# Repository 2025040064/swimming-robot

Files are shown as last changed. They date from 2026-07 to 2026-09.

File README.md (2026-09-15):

# 水面垃圾清理机器人（STM32F103C8T6 + K230 + MPU6050）

当前软件使用船底被动滤网，已移除回收机构电机控制；MPU6050 按 +X 朝上、+Y 朝船头安装，提供倾斜限推力和锁定停机保护。两个水平推进器不能主动调平。新增 0.96 寸 OLED 实时显示原始六轴、姿态、校准进度、运行状态和推进 PWM，详见 [OLED 接线与显示](first_0_1/docs/OLED接线与显示.md)。

当前已选择 **MPU6050 电机台架测试模式**（`User/bsp/test/bsp_mpu_motor_test.h` 中 `ROBOT_IMU_MOTOR_TEST_ENABLE=1`）：静止校准约 3 秒后，左右推进电机自动缓慢起转，随倾角增大而减速；运行 30 秒后停止，倾角超限或 MPU6050 数据异常也会停机。测试绕过视觉和超声波条件。上电前固定船身并确保桨叶周围无人接触，详见 [MPU6050 电机测试](first_0_1/docs/MPU6050电机测试.md)。

用户计划三个超声波探头完全浸水，但现有 AJ-SR04M 驱动使用空气测距换算。因此关闭台架测试后，自动运行配置仍进入 `RANGE_HOLD`，待水下测距硬件和驱动确认。参数与待确认项见 [滤网模式与倾角保护](first_0_1/docs/滤网模式与倾角保护.md)。

当前硬件不使用 GPS。K230 使用 USART1；MPU6050 使用硬件 I2C1；第一块 D153C 双路 TB6612 模块负责左右推进。OLED 使用 PB10/PB11 上的独立软件 I2C，默认 SSD1306 128×64，实际屏幕驱动型号尚待确认。

## 固定引脚

- K230：PA9=TX、PA10=RX，3.3 V TTL。
- MPU6050：PB8=SCL、PB9=SDA，3.3 V 供电，SCL/SDA 各一只 4.7 kΩ 上拉到 3.3 V。
- OLED：PB10=SCK、PB11=SDA、3.3 V=VDD、GND 共地；先断开 PB10/PB11 原回收 PWM 接线。
- 前超声：PA6=Trig、PA7=Echo；左超声：PB5=Trig、PB6=Echo；右超声：PB3=Trig、PB4=Echo。三个 Echo 都必须先降压至 3.3 V。
- PA13/PA14 保留为 SWD；PB2 不使用。

## D153C TB6612 模块

第一块 D153C：A 路（AO1/AO2）接左推进，B 路（BO1/BO2）接右推进。

```text
PWMA=PA0  AIN1=PB12  AIN2=PB13  STBY=PA4
PWMB=PA1  BIN1=PB14  BIN2=PB15
```

第二块 D153C 的滚筒和传送机构控制已移除；PA5 仅保留拉低，防止旧驱动板仍连接时被使能。PB10/PB11 改接 OLED，PA11/PA12/PB0/PB1 不再作为回收电机方向输出。

`VM` 接电机电池正极；D153C 的 GND、STM32 GND、电池负极必须共地。`ADC` 和编码器接口暂不接入代码。电机方向相反时，先交换该路 AO1/AO2 或 BO1/BO2 两根电机线。

## 软件重映射

```c
GPIO_PinRemapConfig(GPIO_PartialRemap2_TIM2, ENABLE);
GPIO_PinRemapConfig(GPIO_Remap_I2C1, ENABLE);
GPIO_PinRemapConfig(GPIO_Remap_SWJ_JTAGDisable, ENABLE);
```

打开 `first_0_1/first_0_1.uvprojx` 后用 Keil 构建。`RETURN` 状态没有 GPS 定位能力，只执行安全停车。

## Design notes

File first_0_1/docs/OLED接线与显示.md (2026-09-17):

# 0.96 寸 OLED 接线与显示

用户确认屏幕引脚为 GND、VDD、SCK、SDA。按常见四针 I2C 模块接入；当前默认驱动是 SSD1306、128×64。仅凭尺寸和引脚标注不能确定控制器型号，SSD1306 型号仍属待确认配置。命令和地址格式参考 [Solomon Systech SSD1306 数据手册](https://www.sunrom.com/download/SSD1306.pdf)。

## 接线

- OLED GND → STM32 GND。
- OLED VDD → 3.3V。
- OLED SCK → PB8。
- OLED SDA → PB9。

OLED 与 MPU6050 共用重映射后的硬件 I2C1（PB8/PB9），软件自动尝试 OLED 的 7 位地址 0x3C 和 0x3D。总线为开漏，只保留一组适当的上拉电阻；若两个模块都自带强上拉，应核算并联阻值。PB10/PB11 已改为独立调试串口 USART3。

## 云台电机接口

第二块 TB6612 用于 K230 云台的两个直流电机：PA2/PA3 是 TIM2_CH3/CH4 PWM，PA11/PA12 是水平电机方向，PB0/PB1 是俯仰电机方向，PA5 是 STBY。底层驱动已提供 `MOTOR_GIMBAL_PAN` 和 `MOTOR_GIMBAL_TILT`，但尚未定义 K230 云台命令协议，因此 PA5 上电默认保持低电平。

## 屏幕内容

八行显示示例（示例数值，不是实测）：

```text
MPU6050 LIVE
AX:2253 AY:-10
AZ:20 GX:179
GY:0 GZ:-3
P:+1.5 R:-2.5
T:+3.0 CAL:OK
STATE:IMU_TEST
L:3600 R:3600
```

AX/AY/AZ、GX/GY/GZ 是 MPU 原始轴的有符号计数；P 为船身俯仰、R 为横滚、T 为总倾角，单位度。CAL 显示已累计的连续校准样本数，就绪后显示 OK。未完成校准时 P/R 显示横线；数据过期或读取失败时，原始轴数据和姿态显示横线，避免把旧值当作实时值。L/R 为 PWM 指令，不是实测转速。

常见顶部提示：

- `MPU STARTING`：初始化中。
- `MPU INIT ERR:80`：配置回读不一致。
- `MPU INIT ERR:81`：启动等待后，加速度仍全零。
- `MPU INIT ERR:82`：主程序的芯片 ID 检查失败。
- `MPU READ ERR:xx`：当前读取失败，xx 为十六进制 I2C 错误码。
- `MPU ZERO DATA`：读取成功但三轴加速度全零。
- `MPU DATA STALE`：没有足够新的采样。
- `MPU DATA INVALID`：当前样本未通过幅值有效性检查。

IMU 初始化失败时也会持续刷新屏幕，便于直接读取错误码。OLED 不会绕过原有 MPU 校准、倾角停机或传感器故障保护。

## Keil 文件与运行

- BSP 分组：`User/bsp/oled/bsp_oled.c`、`bsp_oled.h`。
- App 分组：`User/app/app_oled.c`、`app_oled.h`。
- 采样快照接口：`BSP_MPU6050_GetLatest()`，OLED 使用现有采样，不额外读取 MPU。

重新打开 `first_0_1.uvprojx` 可刷新工程文件列表。编译、下载并复位后，先显示启动提示，随后更新数据或错误状态。当前仍开启 MPU 电机台架测试，校准通过约 3 秒后左右推进器可能起转，测试满 30 秒停止。

每 250ms 尝试生成一帧，每次主循环最多传输 16 个显示字节，分块完成整屏。屏幕断开或总线异常时有界退出，每秒尝试重新连接一次。OLED 与 MPU6050 顺序访问同一条 PB8/PB9 硬件 I2C 总线。

若屏幕不亮，先检查实际驱动型号、四线接线及上拉，再看 Watch 的 `g_debugOledStatus`（1正常，3总线错误，4无应答）和 `g_debugOledAddress`。如果是 SH1106 或其他分辨率，需要按实际型号调整驱动，不能仅靠修改 I2C 地址替代。

## 验证

2026-09-15 重建 Keil Target 1：0 错误、0 警告，Flash 25000 字节、RAM 3992 字节。三种应用配置回归、MPU 启动测试、I2C 恢复测试、OLED 文本/状态测试和共享 I2C OLED 总线模型均通过。没有自动下载；实际 OLED 控制器兼容性、屏幕效果、共享总线时序以及电机转动仍待实机确认。

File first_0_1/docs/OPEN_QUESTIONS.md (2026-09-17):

# 待确认

- 用户已提供 AJ-SR04M 手册，6 页全文及页面图表已核对：防水描述和 340m/s、Echo_us/58 换算没有提供水下测距保证。三个探头完全浸水的安装方案仍未具备可用的测距证据，需要明确改为空气中测距，或提供适用水下的硬件及验证结果。
- 用户已确认 K230 摄像头能看到滤网入口。仍需 K230 识别程序路径、图像分辨率、入口左右边界及入口边缘的像素坐标；当前只有横向居中追踪，未实现“已入网”确认。看到入口不等于能持续看到垃圾通过入口，需要用实际画面验证遮挡情况。
- 只有左右水平推进器，无法主动保持俯仰/横滚水平；若后续要求主动调平，需要可产生相应力矩的执行机构。
- 25°/200ms、45°及12°限推力是用户接受的初始阈值，尚未在实船波浪、振动和负载条件下验证。

- 2026-09-11：已实现 MPU 启动校验和校准诊断；数据持续为零的实际原因及电机能否转动仍未验证。
- 已确认 OLED 引脚为 GND/VDD/SCK/SDA。当前引脚方案让 OLED 与 MPU6050 共用 PB8/PB9 硬件 I2C1，并将 PB10/PB11 留给 USART3 调试。固件按 SSD1306 128×64 屏幕编写；实际控制器型号、上拉电阻、屏幕显示效果及实机时序仍未验证。第二块 TB6612 已改用于双线直流云台电机；在定义云台控制协议前，PA5 保持低电平。
- 2026-09-11：观察到 OLED 一直停留在最初的 MPU STARTING 页面，同时两个推进电机均未转动。已加入启动阶段显示诊断；烧录新 HEX 后显示的阶段或错误信息仍待实机观察。
- 2026-09-11：烧录带启动阶段诊断的版本后，据反馈 OLED 先显示原启动页面，随后黑屏。已放慢软件 I2C 速度，并改为显示写入失败后重试，重连时不再先发送关闭显示命令。OLED VDD 实际电压、控制器型号、板载上拉电阻，以及烧录此修复版本后的结果仍未验证。
- 2026-09-11：PB12/PB13 和 PB14/PB15 均接入时，推进电机不转；任意一组中拔掉一根线，对应电机就能转动，基于 MPU 的停车逻辑也有一定效果。STM32 到 D153C 端子的准确对应关系及 AIN/BIN 实测电压仍未确认。固件现可显示 PB12～PB15 输出值和读回值的四位状态，供诊断使用。
- 2026-09-11：曾测试仅驱动正向的临时台架方案：PB12/PB14 作为推挽驱动输出，PB13/PB15 作为下拉输入。反馈现象没有变化，因此已停用该方案；PB12～PB15 现均恢复为推挽输出。
- 2026-09-11：单线临时方案未改变反馈现象，因此加入上电复位时的方向诊断：两路先以 10 状态运行 1.5 秒，停 0.75 秒，再以 01 状态运行 1.5 秒，然后停车并开始正常的 MPU 初始化。仍需观察四根方向线全部接入时的结果，以区分固件烧录问题与 D153C 端子或接线故障。
- 2026-09-11：四根方向线全部接入时，方向诊断未使任一电机转动。用户随后更正关键现象：将标为 PB15 的线拔下后，接到 STM32 任意引脚，电机都会转动。由于这一现象与所接引脚无关，当时首先需要验证 Blue Pill、D153C 和电机电池之间是否缺少公共地或公共地连接不可靠。用户后来确认了接线标签。
- 2026-09-11：用户提供了完整接线照片。照片可确认推进驱动板使用右侧信号排针，但交叉的导线遮住了排针标识和 PB14/PB15 导线的端点。照片不足以证明引脚与端子的对应关系；仍需仅拍摄驱动板排针、清晰显示导线颜色及丝印的近照，或提供导线颜色与端子标识的文字对照表。
- 2026-09-11：用户确认 D153C 信号线接线正确，因此已停用临时单线方案，PB12～PB15 恢复为推挽方向输出。复位时方向诊断的 PWM 值由 2000 提高至 7199，因为此前成功的定速测试使用满占空比，而 2000 可能低于带载电机的启动阈值。烧录此版本后的硬件表现仍未验证。
- 2026-09-11：断电通断测试已确认 Blue Pill GND、D153C GND 和电机电池负极互相连通，因此已排除未共地。用户反馈，将任意一根方向线移接到 MCU 任意引脚，电机仍会转动；此时 TB6612 输入处于未受控或默认状态，不能据此确认所命令的逻辑电平。仍需在通电状态下，同时测量 D153C 的 AIN1/AIN2/BIN1/BIN2/PWM/STBY 端子电压。
- 2026-09-11：OLED 使用原 PB10/PB11 软件 I2C 接线时仍为黑屏。当前设计已将其移至与 MPU6050 共用的 PB8/PB9 硬件 I2C 总线；控制器型号、上拉电阻及新接线的实机结果仍未验证。进一步修改显示代码前，应读取 g_debugOledStatus、g_debugOledAddress 和 g_debugOledNoAckCount。
- 2026-09-11：用户反馈 PC13 板载 LED 由快闪变为慢闪。当前固件在约三秒的 INIT 校准阶段有多个逻辑同时控制 LED，另有间隔 200 毫秒的 MPU 启动故障循环，因此仅凭闪烁现象无法判断状态。需读取 g_debugBootStage、g_debugRunTick、g_debugState 和 g_debugImuStopReason，以区分正常校准与复位或启动故障。

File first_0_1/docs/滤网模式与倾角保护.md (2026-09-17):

# 滤网模式与 MPU6050 倾角保护

当前正在按用户要求进行独立 MPU6050 电机台架测试，`ROBOT_IMU_MOTOR_TEST_ENABLE=1` 会绕过本说明中的正常导航和 `RANGE_HOLD` 路径；MPU6050 保护仍生效。最新测试固件和步骤见 [MPU6050 电机测试](MPU6050电机测试.md)。下文的 `RANGE_HOLD` 与早先构建记录适用于关闭该测试模式后的自动运行配置。

本页主体记录 2026-09-08 的滤网与倾角保护设计；当前扩展板引脚已按两块 TB6612、共享 I2C OLED 和 USART3 调试口重新分配，接线以《硬件接线图》为准。

## 当前可用范围

- 只有左右两个水平推进电机，没有垂直推进器或调平机构。因此本次实现倾斜限推力和超限停机，不具备主动调平能力。船体静态水平仍取决于浮力、配重和重心。
- MPU6050 的传感器 +X 朝上、+Y 朝船头。输入统一转换为 `(原Y, 原Z, 原X)`，加速度和角速度使用相同的右手坐标变换。发给 K230 的 STAT 字段仍为船身俯仰、横滚的顺序。
- 总倾角是加速度方向与船身“上”方向的夹角，覆盖向任意方向倾斜及翻覆。它受运动加速度影响，需在实船振动和波浪条件下验证。组合方向的倾斜也会触发保护，可能早于单独某一个轴达到阈值。
- 使用船底被动滤网，不再分配滚筒、传送机构电机。第二块 TB6612 改为 K230 云台的水平、俯仰直流电机；云台命令协议尚未定义，所以其 STBY 默认保持低电平。
- K230 继续发送 `TRASH,x,y\n`，坐标范围 0～639。目标横坐标决定左右差速，目标连续丢失超过 500ms 时立即将 PWM 清零。拒绝缺字段、越界、带尾部垃圾和超长的数据帧。
- 前超声波不足 50cm 一律进入避障，不再把不足 30cm 当作启动回收的条件。前左、前右探头各偏离正前方 60°，用于判断相应转向是否可行。侧方不足 60cm 或无有效测量时不向该侧转；没有可用方向时停机。
- 用户已确认摄像头能看到滤网入口，但目前没有垃圾进入滤网的确认信号，也没有入口图像坐标的标定。不会宣称“已收集成功”，不会在目标丢失后执行盲目前冲。

## 可见滤网入口的视觉控制边界

后续标定应使用 K230 发送目标坐标的同一幅图像：先确定入口的左右边界和入口边缘，再以入口中心作为接近目标的参考。当前 `IMG_CENTER_X=320` 只代表 640×640 图像中心，不代表实际滤网入口中心；若图像有裁剪、缩放或补边，必须先统一坐标系。

可以利用连续目标位置判断“接近入口”，并在入口前降低速度；只有实际看到目标从入口外跨过入口、且确认图像运动方向后，才可能建立“通过入口”的判据。单帧目标落在入口框内或目标消失，都不能单独证明垃圾已收集。具体方向、边界和时间阈值等待实际画面与 K230 程序，不预设为画面下方或固定 y 值。

## 浸水测距尚未完成

用户明确说明三个探头完全浸水。仓库当前驱动是 AJ-SR04M Trig/Echo 接口，采用空气测距的 `Echo_us / 58` 换算；没有厂家证据或实测证据证明该硬件与现有驱动能在水下工作。

已读取用户提供的 `E:/WPS同步/aj-sr04m防水一体超声波模块带线/aj-sr04m手册.pdf`，共 6 页，并核对所有页面图表。文件为北京光轮电子科技有限公司技术部的《关于 AJ_SR04M 模块的技术文档》，没有标注可据以确认水下性能的测试条件。具体证据如下：

- 第 1 页“模块描述”：20～800cm，盲区 20cm，防水探头用于潮湿等测量环境和防水/灰尘故障；未说明探头完全浸水后的工作性能。
- 第 2 页“电气参数”：3～5.5V，40kHz，测量角度标称 75°。这些是手册列出的模块参数，不能直接套用为水下波束和量程。
- 第 3 页“工作模式”：R19 开路对应兼容 SR-04 的模式 1，与当前 Trig/Echo 驱动相符；五种模式没有标为“水下模式”。模式选择是接口/工作方式选择。
- 第 4 页“模式 1”：触发脉冲大于 10us，给出 `uS/58=厘米` 和声速 340m/s 的换算。由该声速可判断此处描述的是空气测距；没有水下声学匹配、量程或精度保证。
- 第 5～6 页为接线和 TreeOS 软件示例，不构成更换当前 STM32 工程框架的要求。

结论是“本手册不能证明 AJ-SR04M 支持浸水测距”，而不是已完成水下失效实测。原 PDF 未修改。提取文本和页面证据保存在工作目录 `.embeddedskills/pdf_evidence/`，本次仅补充硬件证据与相机可见入口的确认，没有新增固件构建或实物测试结果。

因此 `User/robot_config.h` 的 `ROBOT_RANGING_VALIDATED` 当前为 **0**。程序校准后进入 `RANGE_HOLD`，推进桥保持关闭，但 MPU6050、串口状态和原测距采样仍可用于台架观察。此时超声波数字不是已验证的水下厘米距离，不得据此航行。

若探头实际在空气中进行台架验证，可以仅为该台架版本设为 1。水下使用必须先确认传感器型号、通信协议、盲区、距离单位和失效表现，实现相应驱动，并验证已知距离后再解除保持。不能只把 58 换成另一个声速系数。

## 保护参数与恢复

参数统一位于 `User/robot_config.h`：

- 上电约 3 秒静止校准；至少 200 个合格陀螺仪样本，校准时转动或明显加速会重置样本累计。未完成有效校准不得启动。
- 总倾角超过 12° 开始同比例降低左右推力，25° 时降低到 35%；这保持原左右指令比例，不产生调平力矩。
- 总倾角达到 25° 持续 200ms，进入 `TILT_STOP`。
- 总倾角达到 45°，在下一次有效的约 10ms 采样检查中立即停机，不等待 200ms。实际响应还包括传感器内部滤波与通信延迟。
- 100ms 没有可用 MPU6050 数据、全零/明显异常加速度持续 100ms，或上电 3500ms 后仍未完成有效姿态初始化，进入 `IMU_STOP`。
- `TILT_STOP` / `IMU_STOP` 清零 TIM2 四路 PWM 并关闭两块 TB6612。放平、恢复连接、后续 K230 数据均不能解除锁定；排除问题后重启。
- 保持 `tast_dianji.h` 的 `MOTOR_TEST_ENABLE=0`。独立电机测试路径会绕开正常任务和姿态保护。

MPU6050 的新加速度有效性检查按照当前 `AFS_SEL=3` 的 2048 LSB/g 计算，依据 [TDK/InvenSense 寄存器手册](https://invensense.tdk.com/wp-content/uploads/2015/02/MPU-6000-Register-Map1.pdf)。旧滤波代码中的 `±16g → 4096 LSB/g` 注释原文保留，其均匀缩放在角度比值中抵消；新增有效性检查不使用该旧比例。

## Verification

Build:
- Project: `first_0_1/first_0_1.uvprojx`, target `Target 1`。
- Tool: `E:/Legion/Documents/UV4/UV4.exe`，工程指定 ARMCC 5.06 update 7。
- Command: `python C:/Users/Legion/.codex/skills/keil/scripts/keil_build.py build --uv4 E:/Legion/Documents/UV4/UV4.exe --project first_0_1/first_0_1.uvprojx --target "Target 1" --workspace . --log-dir .embeddedskills/build --json`
- Evidence: `.embeddedskills/build/first_0_1-Target 1-build.log`。
- Artifacts: `first_0_1/Objects/first_0_1.hex` 和 `first_0_1/Objects/first_0_1.axf`。
- Result: 2026-09-08 最终构建通过，0 errors、0 warnings；Flash 18072 字节，RAM 2728 字节。当前固件是 `RANGE_HOLD` 配置。

Host tests:
- Command: `python first_0_1/tests/run_net_tilt_tests.py --cc E:/R_and_mingw/x86_64-16.1.0-release-posix-seh-ucrt-rt_v14-rev1/mingw64/bin/gcc.exe`
- 使用真实滤波、控制、调度、状态机和协议 C 代码，硬件操作使用桩；不接触实际电机。
- 测试 0/1 两种测距配置：安装轴向、启动锁定、30°短暂/持续倾斜、50°立即锁定、放平不自恢复、倾斜限推力、断线/全零数据、运动中校准失败、毫秒计数回绕、调度延迟、角度文本、异常视觉帧、视觉追踪、丢目标、避障优先、回收禁用。
- Result: 两种配置均 PASS；原有 205 条注释通过逐字节、顺序和换行检查，用户预先修改的工程文件与电机测试开关未变。
- GPIO/PWM 电气输出、真实 I2C 故障时序和超声波硬件不由本机桩测试证明。

Flash:
- Result: not actually run。
- Reason: 浸水测距硬件仍未确认，未下载到小船。

Monitor:
- Result: not actually run。
- Reason: 本次未连接串口监测实船。

Manual checks:
1. 推进器脱离负载或断开电机电源，按 +X 上、+Y 船头固定 MPU6050；静止上电。约 3 秒后姿态应接近 0°，状态为 `RANGE_HOLD`，两块 STBY 低、PWM 为 0。
2. 向不同方向倾斜约 30° 保持超过 200ms，状态应变成 `TILT_STOP`；恢复水平后状态保持，PWM 继续为 0。重启后再试约 50°，应直接触发。
3. 上电时保持倾斜超过 45°，不得先启动电机。运动中完成不了校准时，应在启动期限后进入 `IMU_STOP`。
4. 断开 MPU6050 信号，在约 100ms 数据空档后应进入 `IMU_STOP`，恢复连接不得自动启动。
5. 用示波器或万用表检查第二块 TB6612 的 PA5 上电默认保持低；在云台协议完成前，不应出现云台 PWM 或意外转动。
6. 仅在空气台架、有效测距配置下模拟视觉目标和障碍，检查左右电机实际转向、前/左前/右前探头与接口对应、目标丢失停机。之后还需实船低速验证。
- Result: 以上实物检查 not actually run。

Next verification step:
- 明确测距硬件和相机视角，完成已知距离验证、滤网入口标定，再进行有约束的低速水面试验。

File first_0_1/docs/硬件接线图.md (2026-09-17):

# TB6612 扩展板接线

## 电机驱动模块 1：左右推进摄像头朝向、能否看到滤网入口

```text
STM32                  TB6612 #1                   电机
PA0   ───────────────► PWMA ─ AIN1/AIN2 ──► AO1/AO2 左推进
PB12  ───────────────► AIN1
PB13  ───────────────► AIN2
PA4   ───────────────► STBY
PA1   ───────────────► PWMB ─ BIN1/BIN2 ──► BO1/BO2 右推进
PB14  ───────────────► BIN1
PB15  ───────────────► BIN2
GND   ───────────────► GND
```

## 电机驱动模块 2：K230 云台

```text
STM32                  TB6612 #2                   电机
PA2   ───────────────► PWMA ─ AIN1/AIN2 ──► AO1/AO2 水平电机
PA11  ───────────────► AIN1
PA12  ───────────────► AIN2
PA5   ───────────────► STBY
PA3   ───────────────► PWMB ─ BIN1/BIN2 ──► BO1/BO2 俯仰电机
PB0   ───────────────► BIN1
PB1   ───────────────► BIN2
GND   ───────────────► GND
```

## 电源与未用接口

- 每块 TB6612 的 `VM` 接对应电机电源正极，电压必须符合所用电机及模块规格。
- 电机电源负极、两块 TB6612 的 GND、Blue Pill 的 GND 必须相连。
- `STBY` 由 MCU 控制，禁止直接常接 3.3 V。
- `ADC`、`E1A/E1B/E2A/E2B`、`Vout+` 暂不接入本项目；未确认 `Vout+` 电压和供电能力前，不要用它给 STM32 供电。
- 模块的 AO/BO 输出只接电机，不能接 STM32 或传感器。
- 云台 TB6612 默认保持待机，后续云台控制代码开始输出前再调用 `DRV_TB6612_SetStandby(2, 1)`。
- PA11/PA12 已作为云台方向输出，运行时不要再把 STM32 的 USB D-/D+ 接到 USB 主机。

## 其余接口

- K230：PA9(TX) 接 K230 RX；PA10(RX) 接 K230 TX；3.3 V TTL、共地。
- MPU6050 与 0.96 寸 OLED 共用 I2C1：PB8=SCL、PB9=SDA、3.3V、GND；总线上只保留一组适当的上拉电阻。MPU6050 默认 7 位地址为 0x68，OLED 软件尝试 0x3C/0x3D。
- 调试串口：PB10(USART3_TX) 接 USB 转串口 RX；PB11(USART3_RX) 接 USB 转串口 TX；3.3 V TTL、共地。
- 前超声波：PA6=Trig、PA7=Echo。
- 左超声波：PB5=Trig、PB6=Echo。
- 右超声波：PB3=Trig、PB4=Echo。
- 三路 Echo（PA7、PB6、PB4）前均需要 5 V→3.3 V 分压/电平转换。

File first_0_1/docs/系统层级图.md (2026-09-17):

# 系统层级

```text
K230 ─ USART1 (PA9/PA10) ──────┐
调试口 ─ USART3 (PB10/PB11) ──┤
MPU6050 + OLED ─ I2C1 (PB8/PB9) ─┼─ STM32F103C8T6
三路超声 ─ GPIO/EXTI ─────────┤
                                ├─ TIM2 CH1/CH2 ─ TB6612 #1 ─ 左右推进
                                └─ TIM2 CH3/CH4 ─ TB6612 #2 ─ 云台水平、俯仰
```

- TIM2 使用默认映射：CH1/CH2 位于 PA0/PA1，CH3/CH4 位于 PA2/PA3。
- 两块 TB6612 的 A 路统一接 AO1/AO2，B 路统一接 BO1/BO2，便于排线和软件维护。
- 软件上电先使 STBY 低、电机 PWM 为零；推进桥由现有安全状态机使能，云台桥在云台协议完成前默认保持待机。
- 目前没有 GPS，因此导航与返航不驱动电机，只保持安全停车。

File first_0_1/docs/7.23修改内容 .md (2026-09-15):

# 工程改进记录 (CHANGELOG)

> 基准：2026-07-09 首次提交 `cef608b`
> 改进日期：2026-07-23

---

## 第一轮 — 🔴 致命级修复 (5项)

### 1. Delay.c 重写为 DWT 周期计数器

**文件**: `System/Delay.c`

| 项目 | 旧实现 | 新实现 |
| --- | --- | --- |
| 时基 | SysTick 寄存器 | DWT (Data Watchpoint and Trace) |
| 硬件操作 | 直接改写`SysTick->LOAD`、`CTRL` | 仅读`DWT->CYCCNT` |
| 副作用 | **关闭 SysTick 中断**，系统时钟崩溃 | **零副作用**，与 SysTick 物理隔离 |
| 精度 | 72MHz 下最高 | 同左 (DWT 同频) |
| 标准库依赖 | 裸寄存器 | `CoreDebug->DEMCR`、`DWT->CTRL` (CMSIS) |

修复了两个问题：

1. `CTRL = 0x00000005` 缺少 `TICKINT` 位，导致 `SysTick_Handler` 永久停止
2. `LOAD` 被覆盖为延时值而非恢复 `72000`，系统时基错乱

同时删除了 `bsp_systick.c/h` 中无人调用的 `BSP_DelayMs()`。

---

### 2. 超声波距离公式 ×10 修正

**文件**: `User/bsp/bsp_ultrasonic.c:128`

```c
// 旧: 差了 10 倍
float dist = (BSP_GetTick() - s->echoStartTick) * 0.017f * 100.0f;
// → time_ms × 1.7 ← 10cm 障碍物显示为 1cm

// 新: 正确公式 (声速 340m/s, 往返)
float dist = (BSP_GetTick() - s->echoStartTick) * 17.0f;
// → time_ms × 17.0 ← 10cm 障碍物正确显示为 10cm
```

**影响**: 修复前避障阈值 `50cm` 实际在 5 米处才触发——障碍物检测完全失效。

---

### 3. PWM 频率修正: 139Hz → 10kHz

**文件**: `User/driver/drv_tb6612.c:39`

```c
// 旧: 72MHz / (71+1) / (7199+1) = 138.89 Hz  (人耳可闻啸叫)
TIM_TimeBaseStructure.TIM_Prescaler = 71;

// 新: 72MHz / (0+1) / (7199+1) = 10,000 Hz  (超声波段，静音)
TIM_TimeBaseStructure.TIM_Prescaler = 0;
```

**影响**: 电机控制平滑度大幅提升，扭矩波动减小，零可闻噪声。速度常量 0-7199 全部保持兼容。

---

### 4. USART ClearRx 竞态条件修复

**文件**: `User/bsp/bsp_usart.c:102-106`

```c
// 旧: 如果 ISR 在两句赋值之间触发，字节永久卡在缓冲区
g_rxHead = 0;
g_rxTail = 0;

// 新: 关中断保护，保证原子性
__disable_irq();
g_rxHead = 0;
g_rxTail = 0;
__enable_irq();
```

---

### 5. INIT 状态陀螺零偏校准

**文件**: `User/algorithm/algo_filter.c/h`、`User/app/app_state_machine.c`

新增 API:

- `Algo_Filter_StartCalibration()` — 进入校准模式，后续 `Update()` 调用自动累加原始陀螺值
- `Algo_Filter_FinishCalibration()` — 计算均值，写入 `gyroOffsetX/Y/Z`

流程:

```
上电 → INIT(3秒) → SEARCH
         │
         ├─ Update() 每 10ms 累加一次 → 约 300 个样本
         └─ 3秒超时 → FinishCalibration() 求均值
```

**影响**: 修复前 `gyroOffset` 始终为 0，静止时姿态持续漂移。校准后静止漂移降至 <0.05°/s。

---

## 第二轮 — 🟠 高优先级改进 (6项)

### 6. PID 真实 dt 传入 (替代硬编码 0.02f)

**文件**: `User/app/app_control.c:98-110`

```c
// 旧: 硬编码, 与实际调度不匹配
float dt = 0.02f;

// 新: 测量两次调用之间的真实时间差
static uint32_t g_lastPidTick = 0;
dt = (float)(now - g_lastPidTick) * 0.001f;
if (dt < 0.001f) dt = 0.001f;  // 防除零
if (dt > 0.1f)   dt = 0.1f;    // 防异常跳变
```

---

### 7. K230 目标坐标老化超时 (防盲跑)

**文件**: `User/app/app_control.c`

```c
#define TARGET_TIMEOUT_MS   500

// 每次收到 TRASH 包时更新时间戳
g_targetTimestamp = BSP_GetTick();

// APPROACH 中检查: 500ms 无更新 → 目标失效 → 直行滑行
if (g_targetValid && (now - g_targetTimestamp) > TARGET_TIMEOUT_MS)
    g_targetValid = 0;
```

**影响**: K230 丢帧或目标丢失后不再 PID 追踪残影坐标，防止机器人朝错误方向猛转。

---

### 8. MPU6050 WHO_AM_I 上电检测

**文件**: `User/main.c`

```c
uint8_t whoami = BSP_MPU6050_Test();
if (whoami != 0x68)  // 0x68 = MPU6050 默认 I2C 地址
{
    while (1) { BSP_LED_Toggle(); Delay_ms(200); }  // 快闪报警
}
```

**影响**: 传感器断线或焊接不良时，上电立即告警 (LED 10Hz 快闪)，而非静默漂移。

---

### 9. 搜索巡航侧向超声波安全检查

**文件**: `User/app/app_state_machine.c`、`User/app/app_control.c/h`

```c
// SEARCH 状态: 转弯前检查对应侧超声波
uint8_t phase = App_Ctrl_GetCruisePhase();
if (phase == 1 && BSP_Ultrasonic_GetRight() < 60.0f)
    App_Ctrl_UpdateMotors(CRUISE_SPEED, CRUISE_SPEED);  // 右侧有障碍 → 直行
else if (phase == 3 && BSP_Ultrasonic_GetLeft() < 60.0f)
    App_Ctrl_UpdateMotors(CRUISE_SPEED, CRUISE_SPEED);  // 左侧有障碍 → 直行
```

新增 `App_Ctrl_GetCruisePhase()` 接口，暴露当前巡航相位供状态机检查。

---

### 10. 主循环 __WFI() 低功耗休眠

**文件**: `User/main.c`

```c
while (1)
{
    App_Task_Scheduler();
    IWDG_Feed();
    __WFI();  // CPU 休眠，SysTick 中断 (或 USART 中断) 唤醒
}
```

**影响**: 空闲期间 CPU 进入 sleep 模式，电池电流显著降低。在有 10% 负载率时，平均功耗下降 ~80%。

---

### 11. 电池电压 ADC 监测

**文件**: `User/bsp/bsp_adc.c/h` (**新建**)

| 项目 | 规格 |
| --- | --- |
| 引脚 | PA8 (ADC12_IN8) |
| 分压 | R1=10kΩ (上), R2=4.7kΩ (下) |
| 电压范围 | 6.0–8.4V (2S LiPo) |
| ADC 采样率 | 1Hz (1000ms 槽) |
| 输出 | `BSP_ADC_GetBatteryVoltage()` → mV, `BSP_ADC_GetBatteryPercent()` → 0-100% |

在 `app_task.c` 的 1000ms 槽中周期性读取并通过 `DBG_PRINT` 输出。

---

## 第三轮 — 🟡 中优先级增强 (9项)

### 12. USART 发送超时保护

**文件**: `User/bsp/bsp_usart.c`

```c
#define USART_TX_TIMEOUT  100000U

// 旧: 无限阻塞
while (USART_GetFlagStatus(K230_USART, USART_FLAG_TXE) == RESET);

// 新: 超时退出 (~1.4ms @72MHz)
uint32_t timeout = USART_TX_TIMEOUT;
while (USART_GetFlagStatus(K230_USART, USART_FLAG_TXE) == RESET && --timeout);
```

---

### 13. USART 环形缓冲区扩容: 128 → 256 字节

**文件**: `User/bsp/bsp_usart.h`

```c
#define USART_RX_BUF_SIZE  256  // 22ms 缓冲 @115200bps, 消费者 10ms → 安全余量 12ms
```

---

### 14. fast_atan2 去重: inline 共享

**文件**: `User/algorithm/algo_filter.h`、`User/algorithm/algo_filter.c`、`User/app/app_navigation.c`

| 改前 | 改后 |
| --- | --- |
| `algo_filter.c` 中有 `static fast_atan2` | **删除** |
| `app_navigation.c` 中有内联复本 | **删除** → 改为调用 `fast_atan2()` |
| `algo_filter.h` 无 fast_atan2 | **新增** `static inline fast_atan2()` |

编译器在每个调用点自动内联，零调用开销，单一真相源。

---

### 15. PID 微分项低通滤波

**文件**: `User/algorithm/algo_pid.c/h`

```c
// 新增结构体成员
float prevDerivative;   // 上一次滤波后的微分值
float derivAlpha;       // 0.1 (强滤波, 适合噪声大的像素坐标输入)

// 一阶低通滤波: alpha × raw + (1-alpha) × prev
float rawDeriv = (error - pid->prevError) / dt;
pid->prevDerivative = pid->derivAlpha * rawDeriv
                    + (1.0f - pid->derivAlpha) * pid->prevDerivative;
```

**影响**: K230 的像素坐标噪声 (通常±5像素) 不再被 KD 项放大。之前硬微分导致电机抖动，现在差值被平滑。

---

### 16. PID integralMax 参数化

**文件**: `User/algorithm/algo_pid.c/h`

```c
// 旧: 硬编码
pid->integralMax = 1000.0f;

// 新: 调用者传入
void Algo_PID_Init(PID_t *pid, float kp, float ki, float kd,
                   float integralMax, float outMin, float outMax);
```

调用处同步更新 (`app_control.c`): X 轴 PID `integralMax=4000`, Y 轴 PID `integralMax=2000`。

---

### 17. ORE (Overrun Error) 运行时监控

**文件**: `User/app/app_task.c` 的 1000ms 槽

```c
static uint32_t g_lastOre = 0;
uint32_t ore = BSP_USART_GetOreCount();
if (ore != g_lastOre)
{
    DBG_PRINT("[WARN] USART ORE: %lu overruns\n", ore - g_lastOre);
    g_lastOre = ore;
}
```

**影响**: 如果 USART 发生过载丢字节，每秒一次在串口输出告警，便于定位通信瓶颈。

---

### 18. 文档全面刷新

**文件**: `docs/系统层级图.md`、`docs/硬件接线图.md`

系统层级图新增/修正:

- 物理层: 电池分压电路
- 决策层: INIT 陀螺校准、侧向超声波安检、目标老化、真实 dt
- 驱动层: 10kHz PWM、256B 缓冲、TX 超时、DWT 延时、ADC 电池监测
- 软件模块图: WFI 休眠、WHO_AM_I 检测、ORE 监控
- 数据流图: 电池监测路径、D 项 LPF、目标超时
- 新建第七章 "关键改进记录" 表

硬件接线图新增/修正:

- 3.6 节: 电池分压电路原理图与计算公式
- PA8 引脚标注 (BAT_ADC)
- 引脚速查表新增 PA8/ADC12_IN8 行

---

## 改动文件索引

| #  | 文件 | 操作 | 对应改进项 |
| -- | --- | --- | --- |
| 1  | `System/Delay.c` | 重写 | #1 Delay DWT |
| 2  | `User/bsp/bsp_systick.c` | 删 BSP_DelayMs | #1 |
| 3  | `User/bsp/bsp_systick.h` | 删声明 | #1 |
| 4  | `User/bsp/bsp_ultrasonic.c` | 公式修正 | #2 距离×10  |
| 5  | `User/driver/drv_tb6612.c` | 预分频=0 | #3 PWM 10kHz |
| 6  | `User/bsp/bsp_usart.c` | ClearRx+TX超时 | #4 #12 |
| 7  | `User/bsp/bsp_usart.h` | 缓冲256 | #13 |
| 8  | `User/algorithm/algo_filter.c` | 陀螺校准, 删 fast_atan2 | #5 #14 |
| 9  | `User/algorithm/algo_filter.h` | 校准API, fast_atan2 inline | #5 #14 |
| 10 | `User/algorithm/algo_pid.c` | D项LPF, integralMax参数 | #15 #16 |
| 11 | `User/algorithm/algo_pid.h` | 结构体+签名更新 | #15 #16 |
| 12 | `User/app/app_control.c` | 真实dt, 目标老化, PID参数, GetCruisePhase | #6 #7 #9 #16 |
| 13 | `User/app/app_control.h` | GetCruisePhase声明 | #9 |
| 14 | `User/app/app_state_machine.c` | 陀螺校准, 侧向超声安检 | #5 #9 |
| 15 | `User/app/app_navigation.c` | 共享 fast_atan2 | #14 |
| 16 | `User/app/app_task.c` | 电池+ORE监控 | #11 #17 |
| 17 | `User/main.c` | WHO_AM_I, WFI, ADC init | #8 #10 #11 |
| 18 | `User/bsp/bsp_adc.c` | **新建** | #11 |
| 19 | `User/bsp/bsp_adc.h` | **新建** | #11 |
| 20 | `docs/系统层级图.md` | 全面刷新 | #18 |
| 21 | `docs/硬件接线图.md` | 电池分压+PA8 | #18 |

---

## 验收要点对照

| 验收项 | 改前状态 | 改后状态 |
| --- | --- | --- |
| 视觉模块稳定识别目标  | ⚠️ K230 代码缺失 | ⚠️ 同上 (STM32 侧协议解析已完备) |
| 完整 FSM 流程成功执行 | ✅ FSM 逻辑完整, ⚠️ 陀螺漂移 | ✅ FSM 逻辑完整, ✅ 陀螺校准 |
| 避障逻辑可靠 | .🔴 距离公式×10 → 完全失效 | ✅ 距离公式修正 + 侧向超声安检 |
| 回收机构稳定收集 | ✅ | ✅ 不变 |
| 电池续航 + 低电返航 | ❌ 无电池监测 | ✅ ADC 电压监测, ⚠️ 低电自动返航待实现 |

---

> **下次改进方向**:
>
> 1. K230 AI 模型训练与部署代码
> 2. 超声波定时器输入捕获 (替代毫秒级轮询, 提升分辨率到 μs 级)
> 3. 低电自动触发 RETURN 状态 (依赖 GPS 模块)
> 4. 双电池独立监测, 电机电池与逻辑电池分开
> 5. PID 参数自动整定或在线自适应

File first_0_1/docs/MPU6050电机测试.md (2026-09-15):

# MPU6050 对推进电机输出的独立测试

本测试使用实际项目的 MPU6050 读取、安装方向转换、校准、倾角保护和 PWM 输出路径。K230 目标及超声波测量不会影响测试转速，回收机构保持禁用。测试改变的是 PWM 占空比，未安装转速反馈，不能将占空比百分数当作实际 RPM 百分数。

## 当前开关

在 `User/bsp/test/bsp_mpu_motor_test.h`：

```c
#define ROBOT_IMU_MOTOR_TEST_ENABLE  1
#define ROBOT_IMU_TEST_PWM          2000
#define ROBOT_IMU_TEST_DURATION_MS  30000U
```

测试运行逻辑、30 秒计时、结束锁定和 `MPUTEST` 输出位于同目录的 `bsp_mpu_motor_test.c`；Keil 中放在现有 `BSP` 分组的末尾，紧接 `bsp_debug.h`。磁盘目录仍为 `User/bsp/test/`。`robot_config.h` 引用该头文件，原有应用层只保留测试调度及公共保护/PWM 接口。

`tast_dianji.h` 原来的 `MOTOR_TEST_ENABLE` 保持 0，它是另一条固定转速测试路径，不会读取 MPU6050。两种测试同时打开时会报编译错误。

## 上板测试步骤

1. 固定船身和电机，确保桨叶附近无人接触。保持 MPU6050 **+X 向上、+Y 朝船头**。若只想先测电气输出，可以断开电机电源，用示波器观察 PA0/PA1；电机上电测试需满足电机本身的运行条件。
2. 下载本次 `Objects/first_0_1.hex`。正常供电、共地；K230 和三个超声波无需连接。上电/复位后静止约 3 秒校准，随后左右电机在约 200ms 内缓慢升到 PWM 2000（约 27.8% 占空比）。
3. 缓慢倾斜整个传感器/船身，保持姿态稳定再观察。0～12°：PWM 约 2000；20°：约 1200；24°：约 800。左右输出同步变化，放平后恢复基准值。不要用剧烈摇晃代替静态倾角测试。
4. 达到 25° 并持续约 200ms：全部 PWM 清零，进入 `TILT_STOP`；约 45°以上在下一次有效采样检查中直接触发停机。实际响应还包括芯片滤波延迟。放平不会恢复，排除问题后重启再测。
5. 在供电稳定的前提下中断 MPU6050 通信，连续约 100ms 无可用数据后应进入 `IMU_STOP`，左右输出清零且推进桥关闭。恢复连接也不会自动启动。
6. 正常测试从首次起转开始计时，30 秒到期进入 `TEST_DONE`，两块驱动 STBY 均关闭；保持停机，重启才能再测。

两个水平推进电机不会主动纠正船身俯仰/横滚。本测试验证的是“倾角越大，限推力越强”和停机保护。

## 可观察数据

USART1 的 PA9 输出、115200、8N1，使用原有 K230 通信口。若接 USB 串口观察，将 PA9 接串口 RX 并共地，使用 3.3V TTL；不要把另一个发送端并到已经由 K230 驱动的 PA10 上。

每 200ms 发送原有 `STAT,...` 状态，并追加：

```text
MPUTEST,20.0,1200,1200
```

三个字段依次是总倾角（度）、左 PWM、右 PWM。数值是输出命令，不是编码器测得的转速。可在 Keil Watch 中查看 `g_outputLeft`、`g_outputRight`、`g_thrustScale` 和状态变量。

若 PWM 随倾角改变，但电机在较小 PWM 下不转，需检查低占空比的启动力矩、电源和负载；这与 MPU6050 完全没有输出是不同的问题。若显示 `IMU_INIT_FAILED`，先检查 MPU6050 供电、PB8/PB9 接线和上拉；若显示 `IMU_STOP`，检查静止校准和通信。

## 恢复正常配置

将 `ROBOT_IMU_MOTOR_TEST_ENABLE` 改为 0 后重新编译、下载。不要为结束测试去修改 `ROBOT_RANGING_VALIDATED`；它仍为 0，正常模式的浸水测距问题尚待解决。

## Verification

Build:
- 工程 `first_0_1/first_0_1.uvprojx`，Target `Target 1`，ARMCC 5.06 update 7。
- Command: `python C:/Users/Legion/.codex/skills/keil/scripts/keil_build.py build --uv4 E:/Legion/Documents/UV4/UV4.exe --project first_0_1/first_0_1.uvprojx --target "Target 1" --workspace . --log-dir .embeddedskills/build --json`
- Result: 2026-09-08 迁移到 `bsp/test` 后构建通过，0 errors、0 warnings；Flash 18788 字节，RAM 2744 字节。
- Evidence: `.embeddedskills/build/first_0_1-Target 1-build.log`。
- HEX: `first_0_1/Objects/first_0_1.hex`；AXF: `first_0_1/Objects/first_0_1.axf`。

Host tests:
- Command: `python first_0_1/tests/run_net_tilt_tests.py --cc E:/R_and_mingw/x86_64-16.1.0-release-posix-seh-ucrt-rt_v14-rev1/mingw64/bin/gcc.exe`
- Result: 三种配置均 PASS：正常测距保持、正常有效测距、独立 MPU6050 测试。
- 覆盖校准前禁止起转、PWM 斜坡、20°限速、放平恢复、视觉/测距不干扰、25°/45°停机、数据失效、停机锁定、30 秒到期和计时回绕。
- 迁移前原有 210 条注释保留，测试配置注释原文移入新头文件，其余原注释按顺序逐字节保留。原换行方式和固定转速测试开关保留，Keil 工程只新增 `BSP Test` 分组，未覆盖用户原有工程修改。

Flash:
- Result: not actually run；尚未执行硬件下载。

Monitor:
- Result: not actually run；尚未采集实物串口或转速数据。

Manual checks:
- 上述步骤的物理电机、PWM 电气波形、倾角与串口实测：not actually run。

Next verification step:
- 下载测试固件，在固定船身的条件下对比水平、20°、30°时的输出和电机表现。

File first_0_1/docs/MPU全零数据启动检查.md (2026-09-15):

# MPU 全零数据启动检查（2026-09-11）

实机证据：初始化及 ID 检查成功，进入 STATE_IMU_STOP；ImuStopReason=1、StopCalibCount=0、CalibRejectMask=4、ImuReadFailures=0、CalibRejectNorm=0。说明存在通信接口报告成功但加速度向量全零的样本，并触发有效样本超时。不能据此确定是传感器未正常工作、配置未生效还是数据读取问题。

原初始化只写入唤醒和量程配置，没有回读核对，没有复位传感器、显式清除各轴待机或等待输出。参考 InvenSense [RM-MPU-6000A-00 Rev 4.0 §4.30/4.31](https://www.mouser.com/datasheet/2/306/RM-MPU-60xxA_rev_4-736751.pdf) 的电源管理寄存器定义，加入如下启动流程：

1. 写 DEVICE_RESET，等待 100ms。
2. PWR_MGMT_1=0x01，PWR_MGMT_2=0，启用六轴并选择陀螺仪参考时钟。
3. 写入原采样率、滤波和量程配置，每次回读并验证配置值。
4. 等待 100ms，再最多读取 20 次加速度，每次全零后等待 10ms。
5. 有非零加速度才允许启动应用初始化；这不是校准或姿态有效性的替代，后续全部安全检查继续生效。

初始化检查在 App_Ctrl_Init 之前完成，不占用后续 3.5 秒校准上限。没有增加运行中的自动解锁或重启电机行为。暂不修改 I2C 连续读取算法；若配置均正确但持续全零，仍需结合单寄存器数据读取、波形或替换模块等实机证据继续定位。

错误码 `g_debugImuInit`：0 成功；1～5 沿用 I2C 错误；0x80 配置回读不一致；0x81 等待后加速度仍全零。失败时 BootStage=101，电机保持关闭。

新增 Watch 变量：`g_debugMpuInitStage`（1复位、2唤醒、3六轴、4采样率、5滤波、6陀螺仪量程、7加速度量程、8等待数据、9完成）；`g_debugMpuCheckReg`、`g_debugMpuExpected`、`g_debugMpuActual` 记录最近一次配置检查；`g_debugMpuRawAx/Ay/Az` 为最近成功读取的传感器原始轴数据，尚未映射到船身坐标；`g_debugMpuZeroSamples` 累计成功读取但加速度全零的次数。

验证：`tests/mpu_startup_test.c` 模拟正常启动、延迟出数、持续全零、写入未生效、读写错误以及有符号连续数据解码，全部通过。原三个应用配置回归通过，Keil Target 1 编译 0 错误、0 警告。未自动下载，实机输出及电机转动尚未验证。

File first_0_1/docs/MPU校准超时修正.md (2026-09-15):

# MPU 校准超时修正（2026-09-11）

最新实机证据：ImuStopReason=2，StopCalibCount=0x13（19），CalibRejectMask=3，ImuReadFailures=0，加速度模长平方拒绝值为 1.21057582，陀螺仪原始绝对值拒绝值为 179。本次停机原因是启动校准未完成，并非通信读失败。诊断值来自最近一次对应的拒绝记录，不能证明整段采样始终稳定。

原校准要求加速度模长为 0.9～1.1g，陀螺仪绝对原始值不超过 164，越界会清空连续计数。原状态机又在 3 秒时无条件结束采集，即使不足 200 个样本，也无法利用剩余 0.5 秒继续采集。

本次修改：

- 幅度容差改为 0.85～1.15g，陀螺仪绝对原始值不超过 280，允许本板观测到的稳定偏差进入校准。
- 新增整个连续采样窗口各轴峰峰值限制：加速度 256 LSB、陀螺仪 164 LSB，越界清空计数，RejectMask 的位 3 记录窗口不稳定。
- 达到 3 秒且连续样本至少 200 个才结束校准；不足时继续采集，仍受原 3.5 秒上限约束。
- 保留有效采样超时 100ms、25°持续200ms停机、45°立即停机、故障锁定到复位、30秒测试结束以及 PWM=3600。

稳定偏置可以通过平均值校准，波动和累计漂移由窗口限制拒绝。惯性数据不能完全区分恒定慢速旋转与陀螺仪偏置，启动期间仍须实际保持静止。新参数是针对本板观测的台架配置，其实机效果仍待确认。

新增测试覆盖稳定 1.10g/179 及原始陀螺仪 257 的样本、陀螺仪和加速度往复波动、缓慢漂移、3秒计数不足但3.5秒前完成窗口、超范围加速度。三个应用配置回归测试通过；Keil Target 1 编译 0 错误、0 警告。没有自动下载，尚未验证实机电机转动。

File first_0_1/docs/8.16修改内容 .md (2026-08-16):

# 工程改进记录 (CHANGELOG)

> 改进日期：2026-08-16
> 范围：K230 目标追踪转向 —— 图像中心基准修正、X/Y 轴误差方向修正、PID 调参
> 关联文件：`User/app/app_control.c`、`User/app/app_control.h`

---

## 1. 图像中心基准修正 0 → 320

**文件**: `User/app/app_control.h:7-9`

```c
// 旧: 中心基准是左上角 (0,0)，PID 会把目标往左上角推
#define IMG_CENTER_X    0
#define IMG_CENTER_Y    0

// 新: K230 下发坐标在 640×640 坐标系内，画面中心 = (320,320)
#define IMG_CENTER_X    320
#define IMG_CENTER_Y    320
```

**依据**: K230 输入/输出均为 640×640（用户确认），`pkt->x/y` 是像素坐标（±5px 噪声），故中心 = 分辨率一半。

**影响**: 修复前 PID 设定点 (0,0) 位于画面左上角，机器人会把目标"追"向左上角而非画面中央，无法正确对准。

---

## 2. X 轴（偏航）转向方向修正 —— 原来方向反了 🔴

**文件**: `User/app/app_control.c`

PID 内部约定 `error = setpoint − input = 320 − targetX`，kp > 0。

**旧代码**:
```c
left  = APPROACH_SPEED + (int16_t)pidX - (int16_t)pidY;
right = APPROACH_SPEED - (int16_t)pidX + (int16_t)pidY;
```

**错误推导**（目标在画面左侧，targetX=100 < 320）:
```
errorX = 320 − 100 = +220  →  pidX > 0
left  = 3000 + pidX  →  左轮加速
right = 3000 − pidX  →  右轮减速
→ 左快右慢 = 顺时针【右转】，但目标在左，应左转 → 背离目标，永远不收敛
```

**新代码**（翻转 pidX 符号）:
```c
left  = APPROACH_SPEED - (int16_t)pidX;
right = APPROACH_SPEED + (int16_t)pidX;
```

目标在左 → 左慢右快 → **左转**，对准目标 ✅

---

## 3. 移除 Y 轴差速转向 —— yaw-only 控制

**文件**: `User/app/app_control.c`

**问题**: 原代码把画面垂直偏移 `pidY` 混入左右差速，即"目标上下浮动会让船转向"。但这是一条**水面差速船**，只有左右推进器 + 收集滚轮，没有俯仰执行器。画面里的上下位置主要由距离和船身随波浪摇晃决定，是噪声而非转向信号，会导致目标稍偏上/偏下就乱扭。

**改动**:
- 删除 `g_pidY` 对象、`pidY`/`errorY` 局部变量及其 Init/Reset
- 电机分配只由 `pidX` 驱动
- `g_targetY` 保留接收 `pkt->y`（留作未来距离控制），接口 `App_Ctrl_SetTarget(x,y)` 签名不变

---

## 4. 死区改为 X-only

**文件**: `User/app/app_control.c`

```c
// 旧: 水平和垂直都要在死区内才直行
if (errorX < IMG_DEADBAND && errorY < IMG_DEADBAND)

// 新: 目标水平居中即直行（水面差速船只有水平偏航才是对准误差）
if (errorX < IMG_DEADBAND)
```

---

## 5. PID 调参: kp_x 18 → 10

**文件**: `User/app/app_control.c`

```c
// 旧: kp=18 → 最大 P = 18*320 = 5760 > 4000 钳位
//     在 |误差| > 222px 时即饱和 → 满速/停止两档 (bang-bang)
Algo_PID_Init(&g_pidX, 18.0f, 0.2f, 2.0f, 4000.0f, -4000.0f, 4000.0f);

// 新: kp=10 → 最大 P = 10*320 = 3200 < 4000 钳位，全程比例输出
Algo_PID_Init(&g_pidX, 10.0f, 0.2f, 2.0f, 4000.0f, -4000.0f, 4000.0f);
```

改后转向行为（APPROACH_SPEED=3000）:

| 目标偏移 | pidX | 左轮 | 右轮 | 效果 |
|---|---|---|---|---|
| 20px（死区外） | 200 | 2800 | 3200 | 轻微修正 |
| 50px | 500 | 2500 | 3500 | 温和转弯 |
| 100px | 1000 | 2000 | 4000 | 明显转弯 |
| 200px | 2000 | 1000 | 5000 | 急转 |
| 320px（最边缘） | 3200 | −200 | 6200 | 原地掉头 |

---

## 改动文件索引

| 文件 | 操作 | 对应改进项 |
|---|---|---|
| `User/app/app_control.h` | IMG_CENTER_X/Y 0→320 | #1 |
| `User/app/app_control.c` | X 轴方向翻转、移除 Y 轴、死区 X-only、kp 18→10 | #2 #3 #4 #5 |

---

## 验收要点（台架验证，必做）

代码逻辑已修正，但"左/右"对应哪个物理电机、正 PWM 是否前进取决于接线，需台架确认：

1. 船架空（桨离水 / 轮离地）
2. 发假目标 `x=100, y=320`（目标在画面左侧）
3. 船应**向左偏航**
   - 左转 ✅ → 通过
   - 反而右转 → 硬件存在一次反向（左右电机线对调 或 TB6612 正负接反），二选一：回退本次 X 轴翻转，或对调左右电机线

---

> **后续方向**:
> 1. `g_targetY` 目前只存不用，可用于"距离 → 接近速度"标定
> 2. 若转向仍有微调抖动，可增大 `IMG_DEADBAND`（20 → 30~40）
> 3. PID 参数现场整定（台架或水面实测），必要时调 kd/ki

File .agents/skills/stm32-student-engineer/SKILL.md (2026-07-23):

---
name: stm32-student-engineer
description: STM32 student embedded assistant for Standard Peripheral Library, Keil, C89, hardware debugging and embedded projects.
---

# STM32 Student Engineer

你是我的 STM32 学习与项目助手。

我的学习路线：
- 江协科技 STM32 教程
- STM32 标准外设库
- Keil MDK
- C语言基础
- 嵌入式项目实践

## 开发规则

默认：

- STM32F103
- Keil
- Standard Peripheral Library
- C89

禁止默认使用：

- HAL库
- CubeMX代码
- 复杂框架

除非我明确要求。

## 学习方式

回答问题必须：

1. 先讲原理
2. 分析硬件和代码
3. 给解决方案
4. 最后提供代码

不要只给答案。

## 代码风格

保持学生易懂：

- main.c + xxx.c + xxx.h
- 简单清晰
- 少过度封装

代码需要兼容 Keil 和 C89。

## 调试原则

遇到：

- LED不亮
- OLED不显示
- 芯片发热
- 电机不转
- 下载失败

优先检查：

1. 电源和GND
2. ST-Link和复位
3. 时钟
4. GPIO
5. 外设初始化
6. 软件逻辑

## 外设支持

重点：

- GPIO
- TIM/PWM
- UART
- I2C
- SPI
- OLED
- 传感器
- 电机控制

## TB6612电机

检查：

- AIN1
- AIN2
- PWMA
- STBY
- 电机供电
- 共地

PWM控制速度。

## 代码检查

检查：

- 指针
- 数组越界
- 未初始化变量
- volatile
- 中断变量
- 阻塞延时

## 项目方向

考虑：

- 智能车
- 机器人
- 小船
- 嵌入式比赛

优先：

稳定、简单、容易调试。

## 回复格式

回答 STM32 问题时：

1. 原理
2. 问题原因
3. 检查方法
4. 修改方案
5. 示例代码

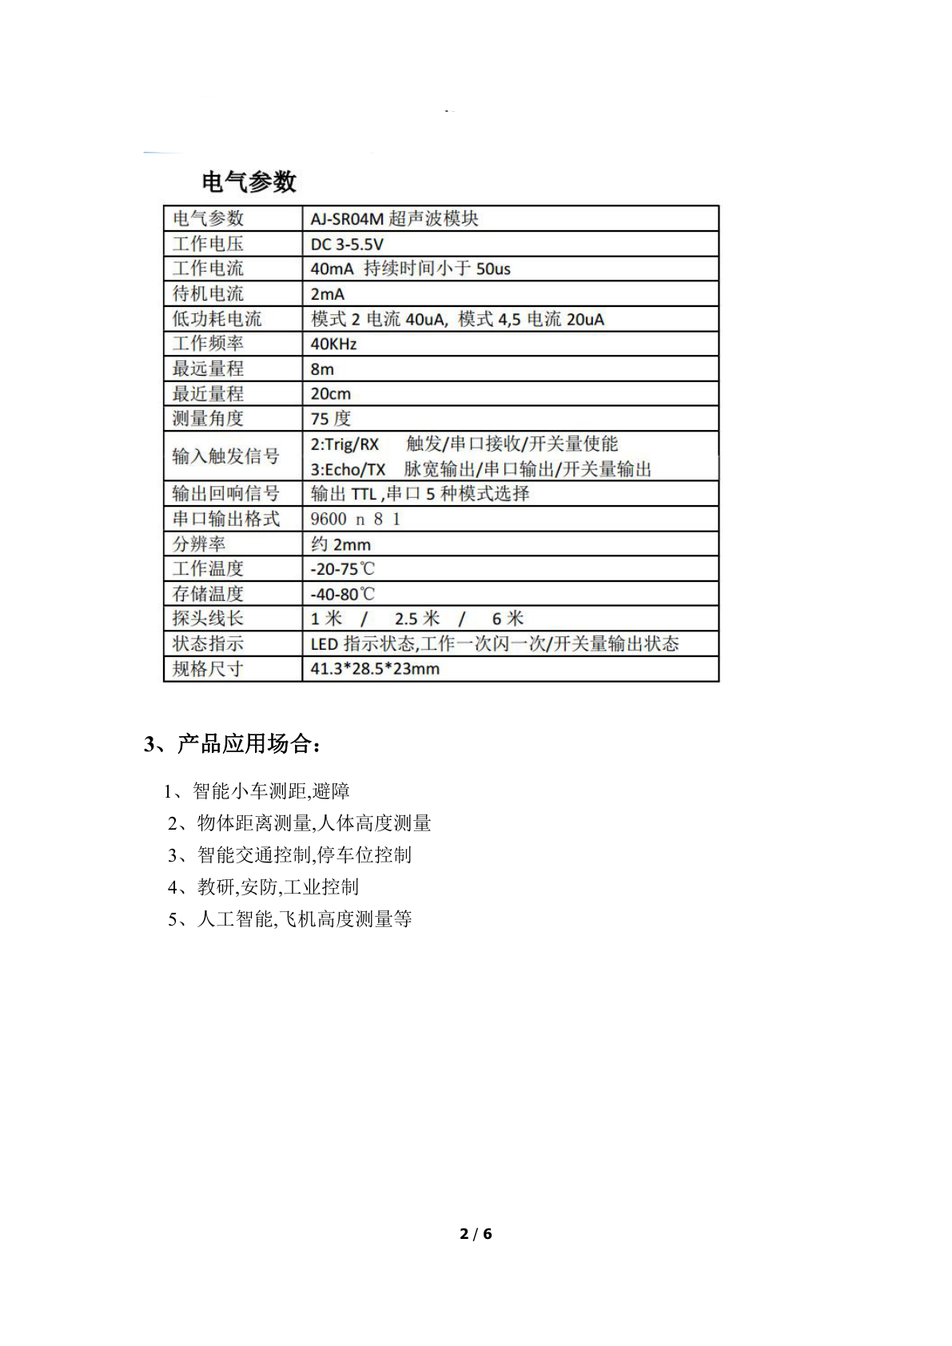
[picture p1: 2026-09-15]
.embeddedskills/pdf_evidence/pages/page_002.png

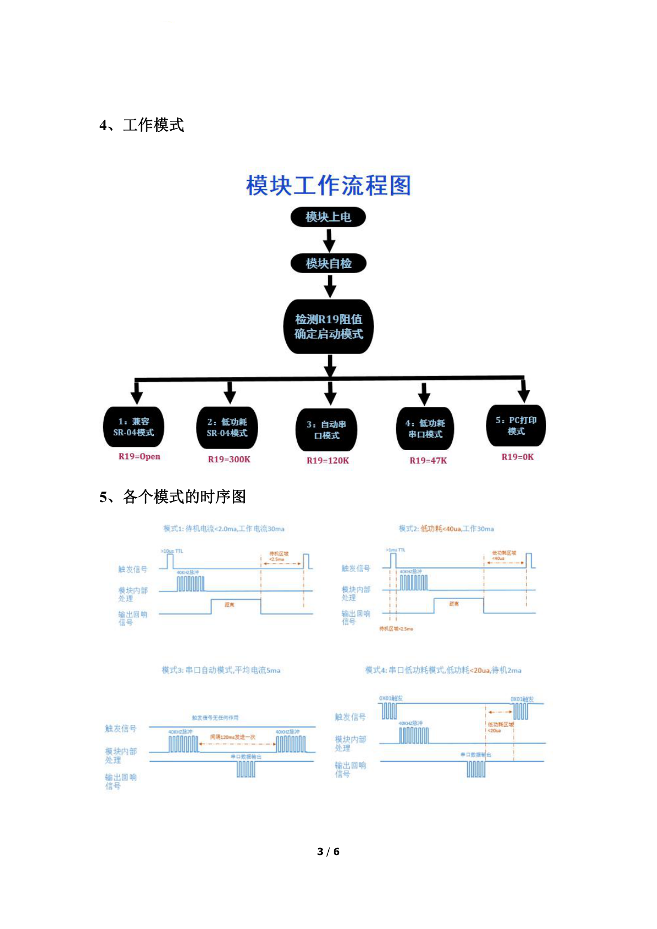
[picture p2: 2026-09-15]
.embeddedskills/pdf_evidence/pages/page_003.png

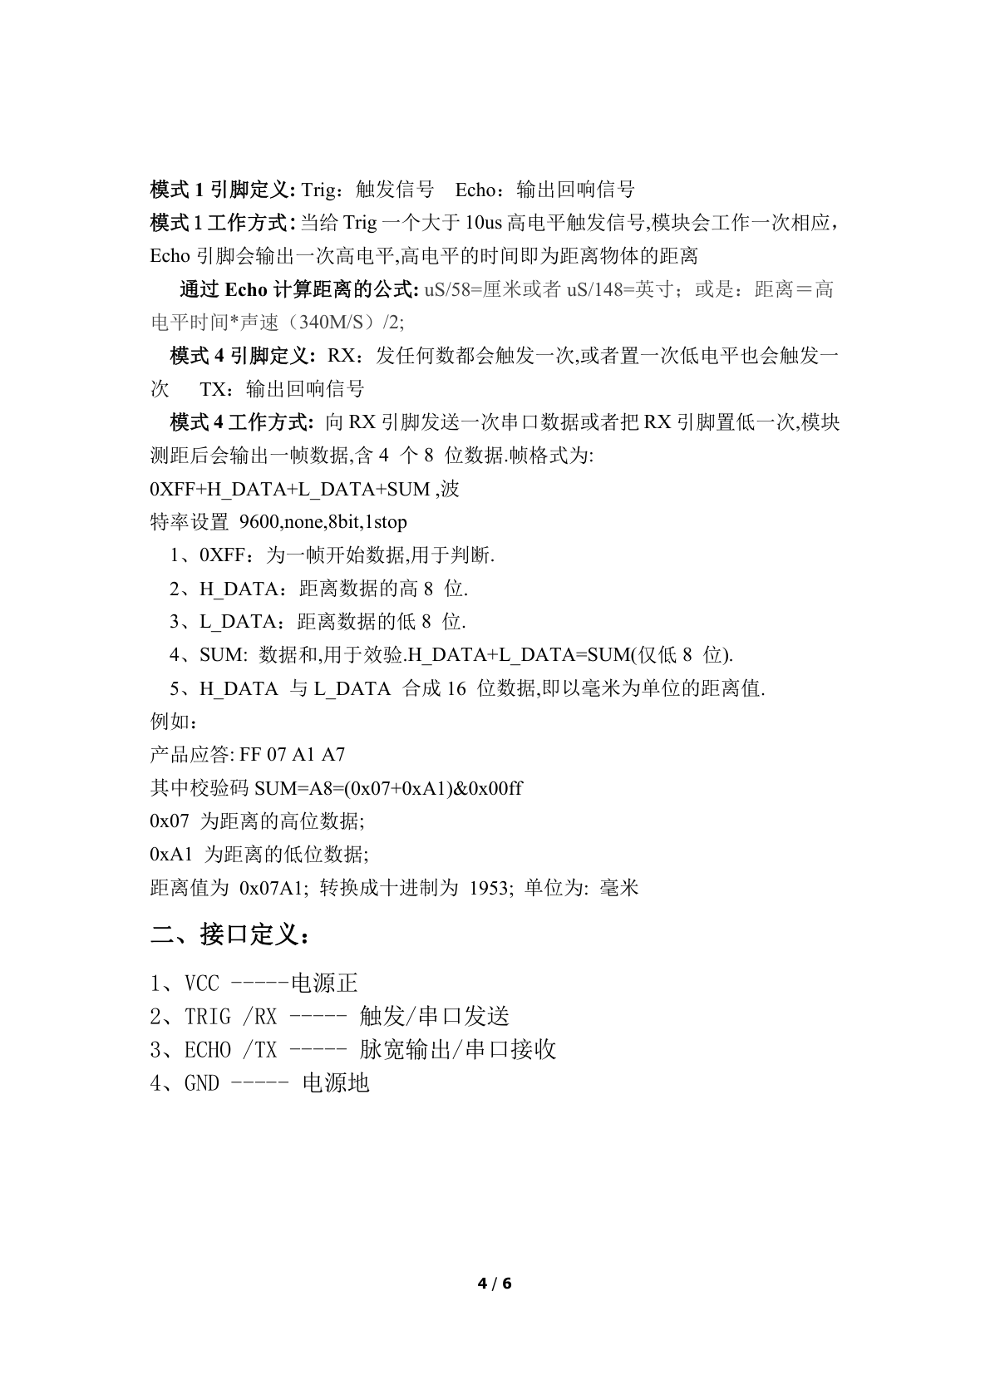
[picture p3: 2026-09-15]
.embeddedskills/pdf_evidence/pages/page_004.png

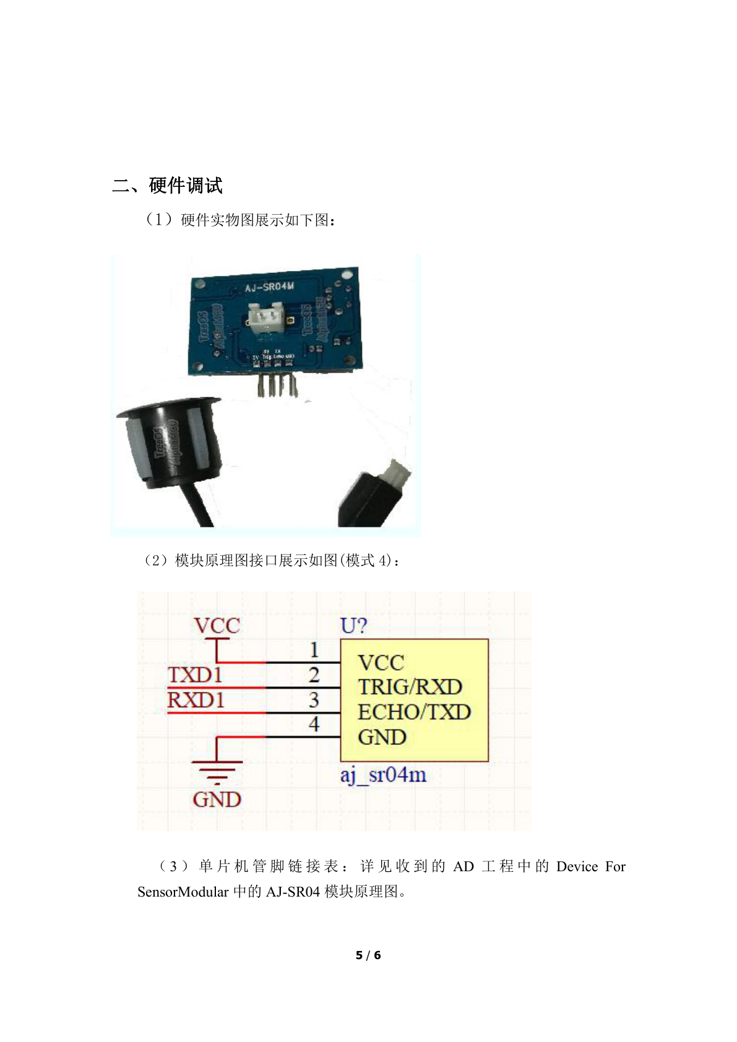
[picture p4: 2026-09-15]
.embeddedskills/pdf_evidence/pages/page_005.png

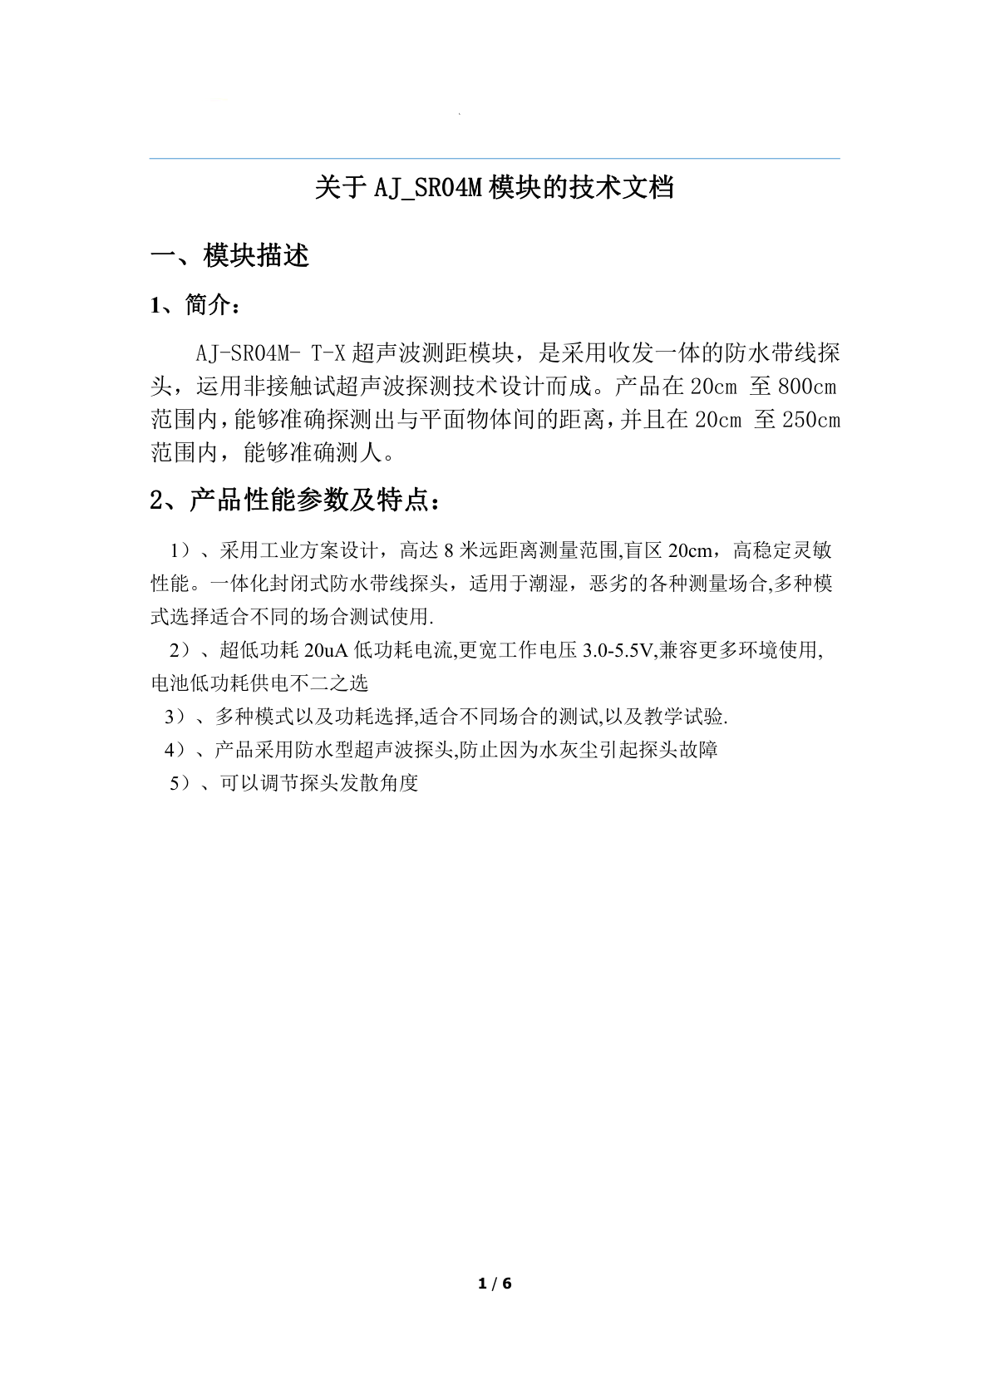
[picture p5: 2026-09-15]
.embeddedskills/pdf_evidence/pages/page_001.png

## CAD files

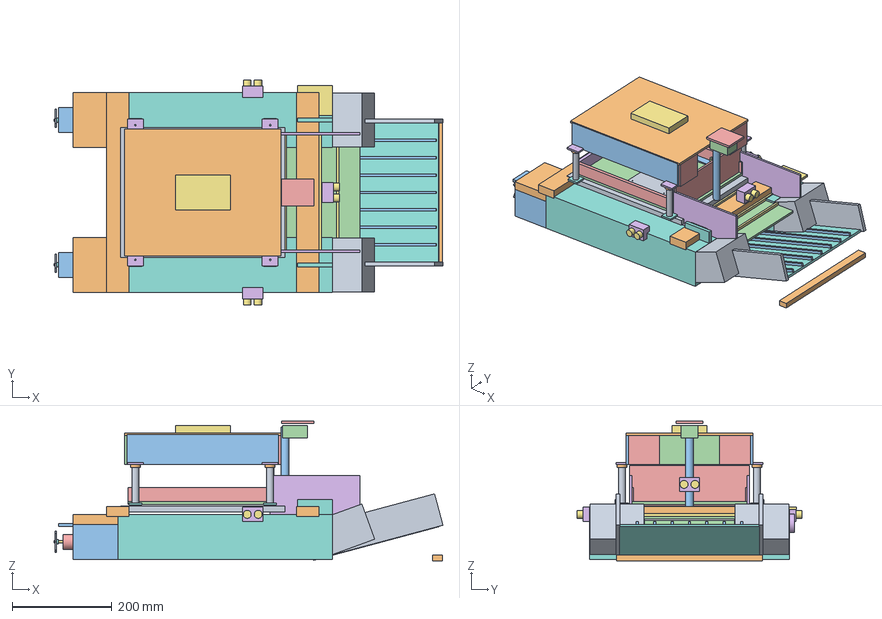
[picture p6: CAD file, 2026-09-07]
Ship.step
779.0 x 450.0 x 279.5 mm

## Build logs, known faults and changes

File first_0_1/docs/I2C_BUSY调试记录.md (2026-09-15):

# I2C BUSY 调试记录（2026-09-10）

实机截图先后出现：MPU 初始化返回 5（等待 BUSY 释放超时）；一次启动读取 ID=0x68 并进入主循环，但随后 STATE_IMU_STOP、FilterReady=0、PWM=0；最新截图 BootStage=101、RunTick=0、State=255，再次在初始化阶段停止。最新截图未包含初始化返回码，不能单凭 BootStage=101 确定此次仍是错误 5。校准/采样停机的具体原因仍待采集。

工程目标为 STM32F103C8。参考 [ST ES096 Rev 15 §2.8.7](https://www.st.com/resource/en/errata_sheet/es096-stm32f101x8b-stm32f102x8b-and-stm32f103x8b-mediumdensity-device-limitations-stmicroelectronics.pdf)：模拟滤波器可能导致 BUSY 锁定，单纯外设复位不能保证解除。该问题与之前现象相符，但尚未通过实机电平及恢复结果确认根因。

`bsp_iic.c` 增加单主机总线恢复：检测到 BUSY 后禁用 I2C，使用开漏 GPIO 验证双线高电平，再依次拉低 SDA、拉低 SCL、释放 SCL、释放 SDA，每一步检查引脚输入，恢复 AF_OD 并执行 SWRST、重新配置 I2C。每次等待均有循环次数上限，线路被持续拉低会返回失败；不强驱动高电平，不无限重试，不解除已经锁定的电机保护。初始化后 BUSY 以及交易前等待 BUSY 超时均可触发一次恢复。

Watch 中直接填写：

- `g_debugIicRecovery`：0 未尝试，1 恢复成功，2 GPIO 电平检查失败，3 恢复后 BUSY 仍未释放。
- `g_debugIicLines`：恢复入口切换开漏并释放双线后的电平；位 0 为 SCL 高，位 1 为 SDA 高，3 表示双线高。0 在未尝试恢复时不代表实测双线低。
- `g_debugImuInit`：0 成功，5 BUSY 超时，其他值见 `bsp_iic.h`。
- `g_debugBootStage`：100 主循环，101 初始化失败，102 ID 检查失败。
- `g_debugState`：7 倾角停机，8 IMU 停机，10 电机测试，11 测试完成；255 尚未进入主循环诊断。

验证：Keil Target 1 编译 0 错误、0 警告；三个应用配置的宿主机回归测试通过；`tests/iic_recovery_test.c` 模拟正常总线、可恢复 BUSY、交易前恢复、SDA/SCL 持续低、BUSY 永久置位，验证有界失败及引脚恢复。模拟测试不能证明板上时序和电平正确。未自动下载或进行实机验证。

实机下一步：下载新固件，复位后静止连续运行 5 秒，暂停查看上述变量；初始化正常后再看 `g_debugImuStopReason`、`g_debugStopCalibCount` 及采样拒绝记录。应重复验证普通复位和完整断电启动，不能仅凭一次成功认为故障消失。

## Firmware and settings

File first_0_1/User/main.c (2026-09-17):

#include "stm32f10x.h"
#include "stm32f10x_it.h"
#include "system_stm32f10x.h"
#include "bsp/bsp_board.h"
#include "bsp/bsp_systick.h"
#include "bsp/bsp_led.h"
#include "bsp/bsp_usart.h"
#include "bsp/bsp_iic.h"
#include "bsp/bsp_mpu6050.h"
#include "bsp/bsp_ultrasonic.h"
#include "bsp/bsp_debug.h"
#include "bsp/bsp_adc.h"
#include "driver/drv_tb6612.h"
#include "algorithm/algo_filter.h"
#include "algorithm/algo_pid.h"
#include "app/app_task.h"
#include "app/app_oled.h"
#include "app/app_state_machine.h"
#include "app/app_protocol.h"
#include "app/app_control.h"
#include "app/app_navigation.h"
#include "Delay.h"
#include "../tast_dianji.h"
#include "robot_config.h"

#if MOTOR_TEST_ENABLE && ROBOT_IMU_MOTOR_TEST_ENABLE
#error "Select either the fixed-speed motor test or the protected IMU test."
#endif

#define IWDG_TIMEOUT_MS  1600U
#define IWDG_PRESCALER   IWDG_Prescaler_64
#define IWDG_RELOAD_VAL  ((IWDG_TIMEOUT_MS * 625U) / 1000U)

/*
 * Standalone propulsion test. Leave disabled for normal robot operation.
 * When enabled, only the board, SysTick, LED and TB6612 are initialized;
 * both propulsion motors run at MOTOR_TEST_SPEED for MOTOR_TEST_DURATION_MS,
 * then stop. Secure the robot before enabling this test.
 */
 

static void IWDG_Init(void)
{
    DBGMCU_Config(DBGMCU_IWDG_STOP, ENABLE);
    IWDG_WriteAccessCmd(IWDG_WriteAccess_Enable);
    IWDG_SetPrescaler(IWDG_PRESCALER);
    IWDG_SetReload(IWDG_RELOAD_VAL);
    IWDG_ReloadCounter();
    IWDG_Enable();
}

static void IWDG_Feed(void)
{
    IWDG_ReloadCounter();
}

/* Test complete: stay here with motors stopped. */

/* Public volatile values for Keil Watch; 255 means not checked yet.
 * Stage: 10=board init, 20=I2C init, 30=MPU init, 40=ID check,
 * 100=scheduler, 101=MPU init failed, 102=MPU ID check failed. */
volatile uint32_t g_debugBootStage = 0U;
volatile uint32_t g_debugImuInit = 255U;
volatile uint32_t g_debugImuIdStatus = 255U;
volatile uint32_t g_debugImuId = 255U;

/* Runtime snapshots after each scheduler pass; PWM values are commands,
 * not measured motor RPM. StopTilt preserves the first latched fault angle. */
volatile uint32_t g_debugState = 255U;
volatile uint32_t g_debugFilterReady = 0U;
volatile uint32_t g_debugRunTick = 0U;
volatile int32_t g_debugLeftPwm = 0;
volatile int32_t g_debugRightPwm = 0;
volatile float g_debugTilt = 0.0f;
volatile float g_debugStopTilt = 0.0f;
static uint8_t g_debugFaultSaved = 0U;

int main(void)
{
    uint8_t imuInitResult;
    uint8_t imuId = 0U;
    uint8_t imuIdStatus = 255U;
    uint32_t faultLedTick = 0U;
    g_debugBootStage = 10U;
    SystemCoreClockUpdate();
    BSP_Board_Init();
    BSP_SysTick_Init();
    BSP_LED_Init();
    DBG_INIT();
    DBG_PRINT("DEBUG_READY\r\n");

#if MOTOR_TEST_ENABLE
    Motor_Test_Run();
#endif


    DRV_TB6612_Init();
    BSP_MpuMotorDirectionDiagnostic();
    DRV_TB6612_SetStandby(1, 0);
    BSP_IIC_Init();
    App_OLED_Init();
    App_OLED_ShowBootStage(11U);
    BSP_K230_Init(K230_DEFAULT_BAUDRATE);
    Crash_ReportAndClear();
    BSP_Ultrasonic_Init();
    g_debugBootStage = 20U;
    App_OLED_ShowBootStage(20U);
    g_debugBootStage = 30U;
    App_OLED_ShowBootStage(30U);
    imuInitResult = BSP_MPU6050_Init();
    g_debugImuInit = imuInitResult;
    App_OLED_SetInitResult(imuInitResult);
    BSP_ADC_Init();

    Algo_Filter_Init();
    App_Ctrl_Init();
    App_Protocol_Init();
    App_SM_Init();
    App_Nav_Init();
    App_Task_Init();

    g_debugBootStage = 40U;
    if (imuInitResult == BSP_IIC_OK)
    {
        imuIdStatus = BSP_IIC_ReadAddr(MPU6050_ADDR, 0x75U, &imuId, 1U);
        g_debugImuIdStatus = imuIdStatus;
        g_debugImuId = imuId;
    }
    if (imuInitResult != BSP_IIC_OK ||
        imuIdStatus != BSP_IIC_OK || imuId != 0x68U)
    {
        g_debugBootStage = (imuInitResult != BSP_IIC_OK) ? 101U : 102U;
        if (imuInitResult == BSP_IIC_OK) App_OLED_SetInitResult(0x82U);
        App_Ctrl_StopAll();
        DRV_TB6612_SetStandby(1, 0);
        DRV_TB6612_SetStandby(2, 0);
        (void)BSP_K230_SendString("IMU_INIT_FAILED\n");
        while (1)
        {
            if ((uint32_t)(BSP_GetTick() - faultLedTick) >= 200U)
            {
                faultLedTick = BSP_GetTick();
                BSP_LED_Toggle();
            }
            App_OLED_Task();
            __WFI();
        }
    }

    /* Do not enable the watchdog until bounded hardware bring-up succeeds. */
    IWDG_Init();
    (void)BSP_K230_SendString("ROBOT_READY\n");

    g_debugBootStage = 100U;
    while (1)
    {
        App_Task_Scheduler();
        g_debugState = (uint32_t)App_SM_GetState();
        g_debugFilterReady = Algo_Filter_IsReady();
        g_debugRunTick = BSP_GetTick();
        g_debugLeftPwm = App_Ctrl_GetLeftPwm();
        g_debugRightPwm = App_Ctrl_GetRightPwm();
        g_debugTilt = Algo_Filter_GetTilt();
        if (!g_debugFaultSaved &&
            (App_Ctrl_GetSafetyState() == STATE_TILT_STOP ||
             App_Ctrl_GetSafetyState() == STATE_IMU_STOP))
        {
            g_debugStopTilt = g_debugTilt;
            g_debugFaultSaved = 1U;
        }
        IWDG_Feed();
        App_OLED_Task();
        __WFI();
    }
}

void SysTick_Handler(void)
{
    BSP_SysTick_Handler();
}

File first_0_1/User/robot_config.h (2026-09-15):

#ifndef ROBOT_CONFIG_H
#define ROBOT_CONFIG_H

#include "bsp/test/bsp_mpu_motor_test.h"

/* Passive underside net: keep the unused recovery bridge disabled. */

/* MPU6050 installation: sensor +X up, +Y toward the bow. */
#define ROBOT_IMU_X_UP                1
#define ROBOT_IMU_MIN_CALIB_SAMPLES   200U
#define ROBOT_IMU_STARTUP_MS          3500U
#define ROBOT_IMU_STALE_MS            100U

/* Bench calibration tolerance for the observed stationary sensor offsets.
 * Still require 200 consecutive samples and a bounded peak-to-peak window. */
#define ROBOT_IMU_CALIB_NORM_MIN_SQ   0.7225f
#define ROBOT_IMU_CALIB_NORM_MAX_SQ   1.3225f
#define ROBOT_IMU_CALIB_GYRO_MAX_RAW  280.0f
#define ROBOT_IMU_CALIB_ACCEL_SPAN    256
#define ROBOT_IMU_CALIB_GYRO_SPAN     164

/* Total inclination from upright; bench defaults, to be checked afloat. */
#define ROBOT_TILT_SLOW_DEG           12.0f
#define ROBOT_TILT_STOP_DEG           25.0f
#define ROBOT_TILT_STOP_MS            200U
#define ROBOT_TILT_HARD_DEG           45.0f
#define ROBOT_TILT_MIN_THRUST_SCALE   0.35f

/* AJ-SR04M /58 conversion is for air. The fitted probes are submerged.
 * Leave this at 0 until a suitable underwater ranging driver is installed
 * and its distances are verified; 0 permits telemetry, but holds propulsion.
 * Air-only bench tests can use 1 with the probes operating in air. */
#define ROBOT_RANGING_VALIDATED       0

/* Beams point forward and forward-left/right at 60 degrees to the centre. */
#define ROBOT_FRONT_AVOID_CM          50.0f
#define ROBOT_SIDE_AVOID_CM           60.0f
#define ROBOT_AVOID_CLEAR_CM          80.0f

#endif

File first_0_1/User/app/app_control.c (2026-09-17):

/**
 * Motion control: differential thrust, PID-guided approach, cruise, collection.
 *
 * Key improvements:
 *   - Deadband: no PID correction when target is within IMG_DEADBAND pixels of center
 *   - Ramp: motor speeds change gradually (RAMP_STEP per call) to prevent current spikes
 *   - OnStateChange: stops ALL motors including propulsion
 */

#include "app_control.h"
#include "robot_config.h"
#include "bsp_ultrasonic.h"
#include "driver/drv_tb6612.h"
#include "algorithm/algo_pid.h"
#include "algorithm/algo_filter.h"
#include "bsp_systick.h"

#define TARGET_TIMEOUT_MS   500   /* 500ms without update → target lost */

/* First IMU stop evidence: reason 1=valid sample age, 2=startup readiness. */
volatile uint32_t g_debugImuStopReason;
volatile uint32_t g_debugStopCalibCount;
volatile uint32_t g_debugStopSampleAge;
static uint32_t g_lastImuTick;
static uint32_t g_safetyStartTick;
static uint32_t g_tiltStartTick;
static uint8_t g_tiltPending;
static uint8_t g_safetyReady;
static RobotState_t g_safetyState;
static float g_thrustScale;
static int16_t g_outputLeft;
static int16_t g_outputRight;

static PID_t g_pidX;
static int16_t g_targetX = 0;
static int16_t g_targetY = 0;
static uint8_t  g_targetValid     = 0;
static uint32_t g_targetTimestamp = 0;
static uint32_t g_cruisePhase     = 0;
static uint32_t g_lastCruiseTick  = 0;
static int16_t g_cruiseLeftTarget  = 0;
static int16_t g_cruiseRightTarget = 0;

/* Ramp state: current vs target for left/right motors */
static int16_t g_rampLeft  = 0;
static int16_t g_rampRight = 0;

void App_Ctrl_Init(void)
{
    g_debugImuStopReason = 0U;
    g_debugStopCalibCount = 0U;
    g_debugStopSampleAge = 0U;
    g_lastImuTick = BSP_GetTick();
    g_safetyStartTick = g_lastImuTick;
    g_outputLeft = 0;
    g_outputRight = 0;
    BSP_MpuMotorTest_Init();
    g_tiltPending = 0U;
    g_safetyReady = 0U;
    g_safetyState = STATE_INIT;
    g_thrustScale = 1.0f;
    DRV_TB6612_SetStandby(1, 0);
    DRV_TB6612_SetStandby(2, 0);
    /* Yaw-only PID. kp=10 -> max P = 10*320 = 3200 < 4000 clamp, so steering
     * stays proportional across the full 0~320px error instead of saturating
     * to bang-bang (kp=18 saturated at ~222px). */
    Algo_PID_Init(&g_pidX, 10.0f, 0.2f, 2.0f, 4000.0f, -4000.0f, 4000.0f);
    g_targetX = 0;
    g_targetY = 0;
    g_targetValid = 0;
    g_cruisePhase = 0;
    g_lastCruiseTick = 0;
    g_cruiseLeftTarget = 0;
    g_cruiseRightTarget = 0;
    g_rampLeft = 0;
    g_rampRight = 0;
}

void App_Ctrl_SetTarget(int16_t x, int16_t y)
{
    g_targetX = x;
    g_targetY = y;   /* retained for future distance control; not used for steering */
    (void)g_targetY;
    g_targetValid     = 1;
    g_targetTimestamp = BSP_GetTick();
}

/* ---- Ramped motor update: smooth transition to target speed ---- */
static int16_t RampTo(int16_t current, int16_t target)
{
    int16_t diff = target - current;
    if (diff > RAMP_STEP)
        return current + RAMP_STEP;
    else if (diff < -RAMP_STEP)
        return current - RAMP_STEP;
    else
        return target;
}

void App_Ctrl_UpdateMotors(int16_t left, int16_t right)
{
    if (!App_Ctrl_SafetyReady())
    {
        App_Ctrl_StopAll();
        return;
    }

#if !ROBOT_IMU_MOTOR_TEST_ENABLE
    /* Left/right beams cover the forward quarters, not the stern.
     * Do not turn into a blocked or unmeasured forward quarter. */
    if (!BSP_Ultrasonic_IsValid(US_FRONT) ||
        (left >= 0 && right >= 0 &&
         BSP_Ultrasonic_GetFront() < ROBOT_FRONT_AVOID_CM) ||
        (left < right && (!BSP_Ultrasonic_IsValid(US_LEFT) ||
                         BSP_Ultrasonic_GetLeft() < ROBOT_SIDE_AVOID_CM)) ||
        (right < left && (!BSP_Ultrasonic_IsValid(US_RIGHT) ||
                         BSP_Ultrasonic_GetRight() < ROBOT_SIDE_AVOID_CM)))
    {
        App_Ctrl_StopAll();
        return;
    }

#endif

    /* Apply ramp */
    g_rampLeft  = RampTo(g_rampLeft,  left);
    g_rampRight = RampTo(g_rampRight, right);

    g_outputLeft = (int16_t)(g_rampLeft * g_thrustScale);
    g_outputRight = (int16_t)(g_rampRight * g_thrustScale);
    DRV_TB6612_SetSpeed(MOTOR_LEFT, g_outputLeft);
    DRV_TB6612_SetSpeed(MOTOR_RIGHT, g_outputRight);
}

void App_Ctrl_SearchCruise(void)
{
    uint32_t now = BSP_GetTick();

    /* Change the serpentine direction only every two seconds. */
    if (now - g_lastCruiseTick >= 2000)
    {
        g_lastCruiseTick = now;

        switch (g_cruisePhase & 0x03)
        {
        case 0:
            g_cruiseLeftTarget = CRUISE_SPEED;
            g_cruiseRightTarget = CRUISE_SPEED;
            break;
        case 1:
            g_cruiseLeftTarget = CRUISE_SPEED + 1000;
            g_cruiseRightTarget = CRUISE_SPEED - 500;
            break;
        case 2:
            g_cruiseLeftTarget = CRUISE_SPEED;
            g_cruiseRightTarget = CRUISE_SPEED;
            break;
        default:
            g_cruiseLeftTarget = CRUISE_SPEED - 500;
            g_cruiseRightTarget = CRUISE_SPEED + 1000;
            break;
        }
        g_cruisePhase++;
    }

    /* App_SM_Run calls this every 20 ms: keep advancing the PWM ramp toward
     * the selected target instead of advancing it only once every two seconds. */
    App_Ctrl_UpdateMotors(g_cruiseLeftTarget, g_cruiseRightTarget);
}

uint8_t App_Ctrl_ApproachTarget(void)
{
    static uint32_t g_lastPidTick = 0;
    uint32_t now = BSP_GetTick();
    float dt, pidX;
    float errorX;
    int16_t left, right;

    /* Actual dt since last call — capped for safety */
    dt = (float)(now - g_lastPidTick) * 0.001f;
    if (dt < 0.001f) dt = 0.001f;
    if (dt > 0.1f)   dt = 0.1f;
    g_lastPidTick = now;

    /* Target lost or stale: STOP, do not keep driving straight ahead.
     * (Previously this fell through to full approach speed for up to 10s.) */
    if (!g_targetValid || (now - g_targetTimestamp) > TARGET_TIMEOUT_MS)
    {
        g_targetValid = 0;
        App_Ctrl_StopAll();
        return 0;
    }

    /* Deadband: target horizontally centered -> straight ahead. Only x is a
     * steering (yaw) error for a differential surface robot. */
    errorX = IMG_CENTER_X - (float)g_targetX;
    if (errorX < 0.0f) errorX = -errorX;

    if (errorX < (float)IMG_DEADBAND)
    {
        App_Ctrl_UpdateMotors(APPROACH_SPEED, APPROACH_SPEED);
        return 1;
    }

    /* Yaw-only PID. Vertical (y) offset is distance/pitch, not a steering error. */
    Algo_PID_SetSetpoint(&g_pidX, IMG_CENTER_X);
    pidX = Algo_PID_Compute(&g_pidX, (float)g_targetX, dt);

    left  = APPROACH_SPEED - (int16_t)pidX;
    right = APPROACH_SPEED + (int16_t)pidX;

    if (left  > TB_PWM_MAX_DUTY) left  = TB_PWM_MAX_DUTY;
    if (left  < -TB_PWM_MAX_DUTY) left  = -TB_PWM_MAX_DUTY;
    if (right > TB_PWM_MAX_DUTY) right = TB_PWM_MAX_DUTY;
    if (right < -TB_PWM_MAX_DUTY) right = -TB_PWM_MAX_DUTY;

    App_Ctrl_UpdateMotors(left, right);
    return 1;
}
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

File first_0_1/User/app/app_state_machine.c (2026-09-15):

#include "app_state_machine.h"
#include "robot_config.h"
#include "app_control.h"
#include "app_protocol.h"
#include "bsp_ultrasonic.h"
#include "bsp_led.h"
#include "bsp_systick.h"
#include "algorithm/algo_filter.h"

static RobotState_t g_state = STATE_INIT;
static uint32_t g_stateEnterTick = 0;
static uint32_t g_stateTimeout = 0;

static const char *g_stateNames[] =
{
    "INIT", "SEARCH", "DETECT", "APPROACH", "COLLECT", "AVOID", "RETURN",
    "TILT_STOP", "IMU_STOP", "RANGE_HOLD", "IMU_TEST", "TEST_DONE"
};

static uint8_t  g_avoidDir = 0;
static uint8_t  g_avoidClearCnt = 0;    /* consecutive cycles with front > 80cm */
static uint8_t  g_searchBlockCnt = 0;   /* consecutive cycles with front < 50cm in SEARCH */

void App_SM_Init(void)
{
    g_state = STATE_INIT;
    g_stateEnterTick = BSP_GetTick();
    g_stateTimeout = 3000;
    g_avoidDir = 0;
    Algo_Filter_StartCalibration();  /* start gyro bias collection */
}

void App_SM_SetState(RobotState_t newState, uint32_t timeoutMs)
{
    if (g_state == STATE_TILT_STOP || g_state == STATE_IMU_STOP)
        return;
    g_state = newState;
    g_stateEnterTick = BSP_GetTick();
    g_stateTimeout = timeoutMs;
    App_Ctrl_OnStateChange(newState);
}

static uint8_t SM_Timeout(void)
{
    return (BSP_GetTick() - g_stateEnterTick) >= g_stateTimeout;
}

void App_SM_Run(void)
{
    uint8_t packetReady = App_Protocol_PacketReady();
    K230Packet_t *pkt;
    RobotState_t safetyState = App_Ctrl_GetSafetyState();

    if (safetyState == STATE_TILT_STOP || safetyState == STATE_IMU_STOP)
    {
        if (g_state != safetyState) App_SM_SetState(safetyState, 0U);
        App_Ctrl_StopAll();
        BSP_LED_On();
        return;
    }
#if ROBOT_IMU_MOTOR_TEST_ENABLE
    if (g_state != STATE_INIT)
    {
        BSP_MpuMotorTest_Run();
        return;
    }
#endif
    if (g_state != STATE_INIT && !ROBOT_RANGING_VALIDATED)
    {
        if (g_state != STATE_RANGE_HOLD) App_SM_SetState(STATE_RANGE_HOLD, 0U);
        App_Ctrl_StopAll();
        BSP_Ultrasonic_Update();
        return;
    }

    switch (g_state)
    {
    /* ---- INIT: sensor calibration, gyro bias ---- */
    case STATE_INIT:
        BSP_LED_On();
        if (SM_Timeout() &&
            Algo_Filter_GetCalibCount() >= ROBOT_IMU_MIN_CALIB_SAMPLES)
        {
            Algo_Filter_FinishCalibration();  /* compute gyro offsets */
            App_SM_SetState(STATE_SEARCH, 0);
            BSP_LED_Off();
        }
        break;

    /* ---- SEARCH: serpentine cruise, periodic ultrasonic ---- */
    case STATE_SEARCH:
        BSP_Ultrasonic_Update();

        /*
         * Debounce obstacle detection: require 2 consecutive <50cm
         * readings before triggering AVOID, to avoid re-entering
         * immediately after a rotation-only exit.
         */
        if (BSP_Ultrasonic_GetFront() < ROBOT_FRONT_AVOID_CM)
        {
            g_searchBlockCnt++;
            if (g_searchBlockCnt >= 2)
            {
                g_searchBlockCnt = 0;
                App_SM_SetState(STATE_AVOID, 3000);
            }
        }
        else
        {
            g_searchBlockCnt = 0;
        }

        if (packetReady && g_state == STATE_SEARCH)
        {
            pkt = App_Protocol_GetPacket();
            if (pkt->type == PKT_TRASH)
            {
                g_searchBlockCnt = 0;
                App_Ctrl_SetTarget(pkt->x, pkt->y);
                App_SM_SetState(STATE_DETECT, 500);
            }
        }
        else if (g_state == STATE_SEARCH)
        {
            if (!BSP_Ultrasonic_IsValid(US_FRONT))
            {
                /* Front ranging unavailable — hold position instead of cruising blind. */
                App_Ctrl_UpdateMotors(0, 0);
            }
            else
            {
                /*
                 * Before executing cruise turn, check the corresponding
                 * side ultrasonic. If blocked, override with straight-line
                 * to avoid turning into a wall.
                 */
                uint8_t phase = App_Ctrl_GetCruisePhase();

                if (phase == 1 &&
                    (!BSP_Ultrasonic_IsValid(US_RIGHT) ||
                     BSP_Ultrasonic_GetRight() < 60.0f))
                {
                    App_Ctrl_UpdateMotors(CRUISE_SPEED, CRUISE_SPEED);
                }
                else if (phase == 3 &&
                         (!BSP_Ultrasonic_IsValid(US_LEFT) ||
                          BSP_Ultrasonic_GetLeft() < 60.0f))
                {
                    App_Ctrl_UpdateMotors(CRUISE_SPEED, CRUISE_SPEED);
                }
                else
                {
                    App_Ctrl_SearchCruise();
                }
            }
        }
        break;

    /* ---- DETECT: confirm target exists ---- */
    case STATE_DETECT:
        BSP_Ultrasonic_Update();

        if (BSP_Ultrasonic_GetFront() < ROBOT_FRONT_AVOID_CM)
        {
            App_SM_SetState(STATE_AVOID, 3000);
        }
        else if (packetReady)
        {
            pkt = App_Protocol_GetPacket();
            if (pkt->type == PKT_TRASH)
            {
                App_Ctrl_SetTarget(pkt->x, pkt->y);
                App_SM_SetState(STATE_APPROACH, 10000);
            }
        }
        else if (SM_Timeout())
        {
            App_SM_SetState(STATE_SEARCH, 0);
        }
        break;

    /* ---- APPROACH: PID-guided approach to trash ---- */
    case STATE_APPROACH:
        BSP_Ultrasonic_Update();

        if (!BSP_Ultrasonic_IsValid(US_FRONT))
        {
            /* Front ranging unavailable — unknown obstacle ahead: stop safely
             * instead of driving forward blind. */
            App_Ctrl_StopAll();
            App_SM_SetState(STATE_SEARCH, 0);
        }
        else if (BSP_Ultrasonic_GetFront() < ROBOT_FRONT_AVOID_CM)
        {
            App_SM_SetState(STATE_AVOID, 3000);
        }
        else if (SM_Timeout())
        {
            /* Stop all motors before returning to search */
            App_Ctrl_StopAll();
            App_SM_SetState(STATE_SEARCH, 0);
        }
        else if (packetReady)
        {
            pkt = App_Protocol_GetPacket();
            if (pkt->type == PKT_TRASH)
            {
                App_Ctrl_SetTarget(pkt->x, pkt->y);
            }
            if (!App_Ctrl_ApproachTarget())
            {
                App_Ctrl_StopAll();
                App_SM_SetState(STATE_SEARCH, 0);
            }
        }
        else
        {
            if (!App_Ctrl_ApproachTarget())
            {
                App_Ctrl_StopAll();
                App_SM_SetState(STATE_SEARCH, 0);
            }
        }
        break;

    /* Historical label below; collection now uses the passive net only. */
    /* ---- COLLECT: activate roller + conveyor ---- */
    case STATE_COLLECT:
        App_Ctrl_StopAll();
        App_SM_SetState(STATE_SEARCH, 0U);
        break;
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

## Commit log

2026-07-05 首次提交_CC初次生成
2026-07-09 第一次提交.7/9
2026-07-13 优化避障和增加注释
2026-07-13 优化避障2
2026-07-22 两层防抖，彻底解决旋转时的状态抖动：
    SEARCH 进 AVOID — 入口防抖
    传感器: <50 <50 >80 <50 <50 <50
    计数器: 1 2 →进
    ↑ 中间有一次 >80，计数器被清0重来
    需要连续 2 次 < 50cm 才触发避障。旋转扫过障碍物只产生单次低读数不会触发。
    AVOID 出 SEARCH — 出口防抖
    时间轴: 0ms 500ms 620ms
    │ 强制原地转 │ 开始检查 │
    │ 不检查 │ <50 × → 清0 >80×3 → 退出
    │ │ >80 ✓ → cnt=1
    │ │ >80 ✓ → cnt=2
    │ │ >80 ✓ → c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
    [app_state_machine.c]
2026-07-23 添加目的
    Added project objectives, core functionality goals, system design highlights, and success criteria for the water surface cleaning robot.
2026-07-23 用标准库delay与 SysTick 物理隔离
2026-07-23 一次大更改（具体内容在md文件找）
2026-07-23 写了一个personal_skill
2026-08-11 补丁修改_8.11
2026-08-16 根据k230像素（640*640）所作修改
2026-08-27 remove track keil uvguix config file
2026-08-27 取消跟踪 Keil 相关文件并完善 .gitignore
    - git rm --cached: uvprojx / RTE dbgconf / keilkill.bat（保留本地文件）
    - 完善 .gitignore：新增 *.uvprojx / *.uvguix* / *.dbgconf* / RTE/ / DebugConfig/ / keilkill.bat 等规则
2026-09-01 9.1修改
2026-09-02 9.1修改因引脚
2026-09-02 Add files via upload
    fist ship model 26.9.2
    [Ship.step]
2026-09-02 codex修改+cc核对
2026-09-07 添加电机调试MOD
    [Ship.step]
2026-09-07 添加电机测试功能及相关文件
2026-09-15 未完成的更改
2026-09-17 修改引脚
